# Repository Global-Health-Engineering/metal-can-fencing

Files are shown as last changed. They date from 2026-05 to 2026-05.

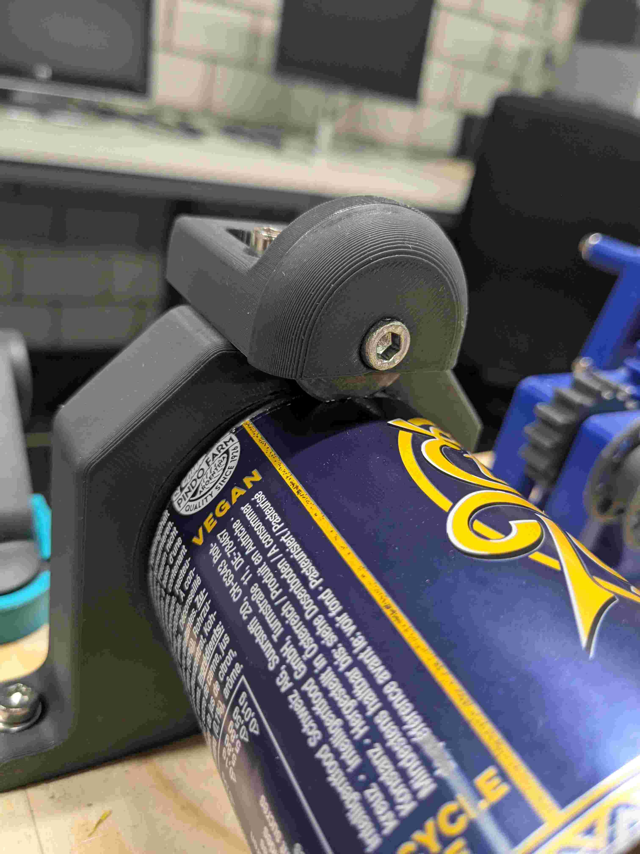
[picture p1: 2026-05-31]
media/photo/PXL_20260528_091816733.jpg

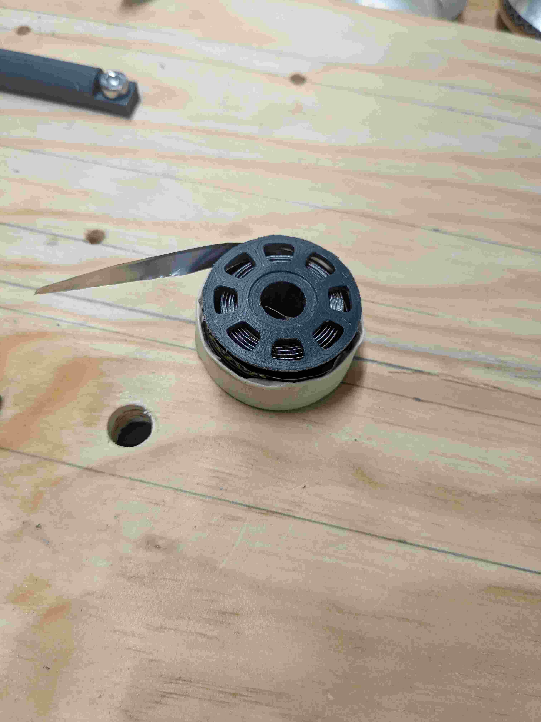
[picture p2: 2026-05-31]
media/photo/PXL_20260528_092012684.jpg

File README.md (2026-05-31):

# metal-can-fencing

# Aluminium Can Wire Prototype
**Semester Project at Global Health Engineering, ETH Zürich**

The repo contains the project files of a prototype machine for turning waste aluminium cans into wire intended to be used for fencing. A detailed description of the project background can be found in the proposal document. 

---

## CAD Model

The CAD Model of the protoype is available as a public document here:
**[Main Prototype CAD](https://cad.onshape.com/documents/85e6de6017a37f12d6a3c2e9/w/624e25fabe076b6094cd570a/e/ef13d64fd9b0a9b642ac96d9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)**

The .stl files are also available for download in the hardware folder of this repository.
A part list with everything necessary for the construction of the prototype is in the docs folder.

---
## Video Demonstration

**[Fencing Wire from Waste Cans: Prototype Demonstration](https://youtu.be/PfGfU24g3dw)**

---

## Repository Structure

```

├── docs/
│   ├── zanggerf_proposal.pdf   # Research proposal with background information on project
│   ├── part_list.xlsx         # List of all parts needed for the construction
|   └── parameter_testing.xslx  # Excel sheets of can dimensions, tested wire types and optimized parameters
│
├── media/
│   └── photo/  # Images of the prototype and different wire types tested
│
├── hardware/            #.stl files of the 3D printed parts of the prototype
|   ├── non_print_parts/      # Parts to be bought/manufactured not printed 
|   ├── opener/
|   ├── slicer/
|   ├── transmission/
|   └── twister/ 
│
└── README.md
```

---

## Contact

Feel free to contact Fabian Zangger (fabian.zangger@hotmail.com) if you have questions regarding the project.

---

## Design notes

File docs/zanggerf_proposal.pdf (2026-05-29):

June 2023 | 1 of 6

## Origami Fencing from Waste Cans

Fabian Zangger

Background

Solid Waste disposal in Sub-Saharan Africa

Proper management and disposal of solid waste is crucial, as open dumping and burning have enormous negative impacts both on public health and on the environment (Adedara et al., 2023; Ferronato & Torretta, 2019). The annual waste generation in sub-Saharan Africa has been increasing and is expected to keep doing so as populations and economies grow, while solid waste collection and coverage rates are still far below satisfactory at around 65% (Ferronato & Torretta, 2019).

Aluminium Recycling in Malawi

Aluminium and other scrap metal is collected in Malawi by waste pickers but is mostly exported to other countries rather than being recycled in Malawi (Kasinja & Tilley, 2018). It is also frequently turned into artisanal cookware, which is a health risk due to metal leaching into the food when using the

recycled cookware (Street et al., 2020).

Resource shortages in Malawi

Malawi suffers from resource shortages, leading to delays in construction projects and making construction materials essentially unavailable for many (Moses & Wynand, 2013). Theft of valuable resources such as aluminium cables only worsen the situation (Beston, 2025). Farmers that require fencing to protect their produce from grazing goats cannot afford to build a fence from conventional materials.

Requirements for goat suitable fencing

The practise of letting goats roam free leads to the problem of farmers crops being consumed and destroyed by the goats (Rumosa Gwaze et al., 2008). To protect the crops from the goat herds, suitable fencing must be used. The fencing must not present a danger to the goats, e.g. it mustn’t have sharp edges that injure the animals or have loose strings in which they can entangle and hurt themselves (Paige, 2008). At the same time, the fencing needs to be high enough to stop the goats from jumping it, and reach to the ground so the animals cannot slip under it (Lund & May, 2003).

Aluminium can upcycling

Various methods to upcycle aluminium beverage cans already exist and have been documented online. Project Kamp, a community research project for more sustainable living, has built a roof from shingles made up of aluminium cans that were cut up and flattened (Cheung & Hakkens, 2023). Keving Cheung designed a can slicer, intended to quickly and cleanly cut off the top and bottom parts of aluminium cans, leaving a sheet metal cylinder (Cheung, n.d.). Other creators turned used beverage cans into low voltage electric wiring (CircuitsReuse, n.d.) or even jewellery.

Problem statement and goals

Aluminium beverage cans in Malawi are being collected, but do not get recycled. Farmers need fencing to protect their crops from roaming goats, but can’t afford them. The goal of this project is to design a method to upcycle empty aluminium beverage cans into fencing. The fencing design has to be robust enough to hold back goats without posing an injury risk to the animals. A prototype machine for the cutting and folding of the cans is to be developed. The machine must be simple to manufacture in low resource environments and easy to operate and maintain.

Research Questions

1. How can aluminium beverage cans be turned into fencing suitable for managing goats?
2. What is the tensile strength that can be achieved with a fence made of aluminium wiring?
3. How can a machine facilitate and speed up the process of fence manufacturing?

Methods

1. Requirements for goat fencing will be researched and commercially available fencing designs will be studied. Aluminium beverage cans will be cut into strips or sheets. A method for interlocking the strips to form a wire will be determined experimentally. Inspiration from origami techniques could be used to find a satisfactory method. The aluminium wiring could then be woven into mesh to increase the fencings strength. Metrics to categorise the resulting fence designs could include the tensile strength, how much of an individual can can actually be used (or how much of it ends up as scrap), how many steps are required in the manufacturing process or how many cans are required per meter of fence.
2. The tensile strength of the resulting fence designs will be measured. Additionally, the durability to different kind of stresses could be tested, such as simulating goats chewing on the wiring or ramming it. This may be a crucial weakness, as the thin aluminium from the cans is very prone to fatigue fractures after bending just a few times.
3. For the resulting fencing design, the relevant manufacturing steps will be analysed. A machine will be designed to aid in carrying out the manufacturing steps. A prototype of the machine will be built and tested. The machine will be designed to be easy to manufacture from locally available resources. It will be portable and powered by hand (e.g. via a hand crank) to allow it to be used anywhere. The prototype of the machine could then be further improved and implemented in Blantyre, Malawi, as part of a master’s thesis. The prototype will presumably be built using 3D printed and / or laser cut parts, to allow for rapid prototyping.

Planning

Gantt chart

I am doing this semester project part time, from the 02.03. to the 29.05.

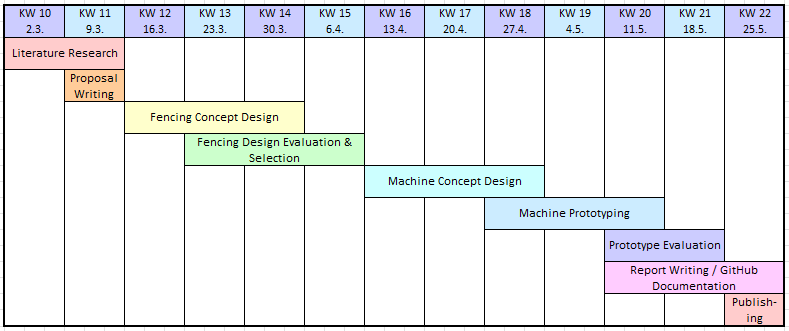
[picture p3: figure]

Figure 1. Gantt chart for research work and thesis writing.

After some initial research I will start to develop and build some fence concepts from cans by hand. The robustness and strength of the fence designs will then be tested and the results used to improve the designs. It may turn out that aluminium breaks to quickly from fatigue, which could be a potential showstopper. Once the best fence design is determined (one that is not too complex to build in as few as possible steps, yet robust enough), a concept for how to mechanise the production will be developed. I plan to start prototyping early and quickly using 3D printed parts. The last two to three weeks I will focus on evaluating the prototype and reporting my results. If the results are promising I would like to then continue with the project for my master’s thesis.

Data Management Plan (DMP)
Data collection

I am not planning to collect survey data. The only data I will be dealing with is the fencing designs and machine parts that will be developed. Some variables may be used to characterize and evaluate the fencing designs such as:

- Tensile strength
- Material cost (Cans / meter)
- Manufacturing complexity
- Efficiency in can usage (how much of a can is actually used for the fencing)

Data storage

The fence designs and their characteristic variables will be stored in an excel sheet, where they can easily be compared to each other. The CAD Drawings of the machine prototype will be stored in a GitHub repository that will be used to document the entire project.

Budget

I can only give a rough estimate for the costs of the prototype, but I expect to remain under 100 CHF for the total material costs. The main expenses will be the knives for the cutting of the aluminium, plywood to build a solid base and some screws and nuts to fit the parts together.

No | expense | amount | unit price [CHF] | total price [CHF]
1 | 3D Printing Filament | 1 kg | 20 | 20
2 | Knives / Razor Blades | 5 | 5 | 25
3 | Screws etc. | 20 | 2 | 40
4 | Plywood | 1 | 15 | 15
Total | 100
dataset | data type | data format | data documentation
Fence designs | Concepts of fencing designs | Drawings / Images | Stored in a document on GitHub repo
Fence Characteristics | Variables describing the performance of the fence designs: • Tensile strength • Material Cost • Manufacturing Complexity • Can usage Efficiency | Excel table | Stored in a document on GitHub repo
CAD Drawing | Model of the Machine | .stl files | Stored on GitHub repo

References

Adedara, M. L., Taiwo, R., & Bork, H.-R. (2023). Municipal Solid Waste Collection and Coverage

Rates in Sub-Saharan African Countries: A Comprehensive Systematic Review and Meta-

Analysis. Waste, 1(2), 389–413. https://doi.org/10.3390/waste1020024

Beston, L. (2025, November 24). The Power Thieves of Thyolo: Inside Malawi’s Silent War Against

Infrastructure Vandalism. Zodiak Malawi. https://zodiakmalawi.com/national-news/news-in-

the-southern-region/the-power-thieves-of-thyolo-inside-malawis-silent-war-against-

infrastructure-vandalism

Cheung, K. (n.d.). Can Slicer. Kevin Cheung. Retrieved 5 March 2026, from http://kevin-cheung.com

Cheung, K., & Hakkens, D. (2023). Aluminium Can Roof. Project Kamp Community.

https://community.projectkamp.com/research/can-we-make-a-roof-from-recycled-

aluminium-cans

CircuitsReuse, B. (n.d.). Repurposing Beverage Cans for Low Voltage Electrical Wiring.

Instructables. Retrieved 9 March 2026, from https://www.instructables.com/Repurposing-

Beverage-Cans-for-Low-Voltage-Electric/

Ferronato, N., & Torretta, V. (2019). Waste Mismanagement in Developing Countries: A Review of

Global Issues. International Journal of Environmental Research and Public Health, 16(6),

1060. https://doi.org/10.3390/ijerph16061060

Kasinja, C., & Tilley, E. (2018). Formalization of Informal Waste Pickers’ Cooperatives in Blantyre,

Malawi: | A | Feasibility | Assessment. | Sustainability, | 10(4), | 1149.

https://doi.org/10.3390/su10041149

Lund, | R., | & | May, | T. | (2003). | Goat | Fencing. | NSW | Agriculture.

https://www.dpi.nsw.gov.au/__data/assets/pdf_file/0005/178502/goat-fencing.pdf

Moses, K., & Wynand, S. (2013). Causes of delay in road construction projects in Malawi. Journal

of | the | South | African | Institution | of | Civil | Engineering, | 55(3).

https://www.scielo.org.za/pdf/jsaice/v55n3/09.pdf

Paige, C. (2008). A Landowner’s Guide to Wildlife Friendly Fences. Montana Fish, WIldlife & Parks.

https://www.nrcs.usda.gov/sites/default/files/2022-09/WildlifeFriendlyFences.pdf

Rumosa Gwaze, F., Chimonyo, M., & Dzama, K. (2008). Communal goat production in Southern

Africa: | A | review. | Tropical | Animal | Health | and | Production, | 41(7), | 1157.

https://doi.org/10.1007/s11250-008-9296-1

Street, R. A., Mathee, A., Tanda, S., Hauzenberger, C., Naidoo, S., & Goessler, W. (2020). Recycling

of scrap metal into artisanal cookware in the informal sector: A public health threat from multi

metal exposure in South Africa. Science of The Total Environment, 699, 134324.

https://doi.org/10.1016/j.scitotenv.2019.134324

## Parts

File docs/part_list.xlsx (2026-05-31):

Part Name | File name | Amount required | How to make | Link | Description
Baseplate | baseplate.stl | 1 | cut to shape and drill holes according to drawing |  | 10 mm Wooden plate on which everything is mounted
Can Clamp | can_clamp.stl | 1 | print and insert m3 threaded inserts |  | Clamp to mount can on axis
Opener Bottom | opener_bottom.stl | 1 | print |  | blade holder for opening mechanism bottom
Opener Bottom Cover | opener_bottom_cover.stl | 1 | print |  | Blade cover for bottom of opener
Opener Top Half | opener_top.stl | 1 | print |  | Top half of opener
Opener Top Cover | opener_top_cover.stl | 1 | print |  | Blade cover for top of opener
Rail | rail.stl | 2 | print |  | Rail to guide opener along axis
M10x80 Hex Screw |  | 3 | buy | https://www.hornbach.de/p/sechskantschraube-m-schaft-din-931-m10x80-mm-galv-verzinkt-50-stueck/5217648/ | Used as axes for opened height adjustmen and for the gearbox
M3 Heat Set Inserts |  | 4 | buy | https://www.amazon.com/Kadrick-Threaded-Assortment-Printing-Components/dp/B0DLSLJSK7 | Used to secure that can wont rotate inside clamp and for crank handle
M5x30 Allen Screw |  | 20 | buy | https://www.hornbach.ch/de/p/dresselhaus-innensechskantschraube-zylinderkopf-antrieb-teilgewinde-5-0-x-30-mm-galvanisch-verzinkt-100-stueck/6834955/ | Used for almost all connections to baseplate and to mount blades
M5 Hex Nut |  | 20 | buy | https://www.hornbach.ch/de/p/sechskantmutter-din-934-m5-galv-verzinkt-100-stueck/3830634/ | '
M5 Washer |  | 20 | buy | https://www.hornbach.ch/de/p/unterlegscheibe-din-9021-5-3-mm-edelstahl-a2-100-stueck/3836695/
Olfa RB28-2 |  | 5 | buy | https://www.hornbach.ch/de/p/olfa-ersatzrundklingen-rb28-2-2er-pack/3896117/ | Circular blades to
Can Slicer Base | slicer_base.stl | 1 | print |  | Mounts slicer tube to baseplate
Slicer Tube | slicer_tube.stl | 1 | print, then cut 0.6mm groove at 2° to fit blade |  | guide for can cylinder during slicing
Slicer Blade Mount | blade_mount.stl | 1 | print, insert m5 heat set insert |  | adjustable blade mount to allow for different thickness of strip
M5 Heat Set Insert |  | 3 | buy | https://www.amazon.com/Kadrick-Threaded-Assortment-Printing-Components/dp/B0DLSLJSK7 | used to mount blade on slicer
Slicer Blade Cover | slicer_blade_cover.stl | 1 | print |  | covers blade to protect fingers
Coil Center | coil_center.stl | 1 | print |  | center of coil that winds up sliced strips
Coil Wall | coil_wall.stl | 2 | print, then glue to center with fillet to inside |  | walls of coil
Coil Sleeve | coil_sleeve.stl | 1 | print |  | sleeve for coil to prevent unwinding by itself
Twister Axle | twister_axle.stl | 1 | print |  | axle to mount full coil on
Twister Lever | twister_lever.stl | 1 | print, then insert m3 threaded insert |  | lever to off center coil for spinning
Wire Guide | wire_guide.stl | 1 | print |  | guides the wire while twisting
Gearbox Mount Crankside | gearbox_mount_crankside.stl | 1 | print |  | guides for the axes
Gearbox Mount Coilside | gearbox_mount_coilside.stl | 1 | print |  | guides for the axes
Coil Axle | coil_axle.stl | 1 | print |  | axle to mount coil on
45 Teeth Gear | gear_45.stl | 1 | print, secure on axis with nuts |  | 45 teethed gear to speed up machine
15 Teeth Gear | gear_15.stl | 1 | print |  | 15 teethed gear
Hex Crank | hex_crank.stl | 1 | print, thread onto hex screw axle & fix with inserts |  | lever handle to spin axis
Handle m5 | handle_m5.stl | 1 | print, attach to crank with m5 screw |  | handle to grip onto
Prusa Adapter | prusa_adapter.stl | 1 | print |  | adapter for prusament spool to fix it on baseplate for wire winding
Axle 50mm | axle_50mm.stl | 1 | print |  | axle to mount filament spool on

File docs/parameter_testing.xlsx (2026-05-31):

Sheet: Can Dimensions
Can Type | Diameter [mm] | Height [mm] | Bottom Height [mm] | Top Height [mm] | Bottom Ring Diameter [mm] | Top Ring Diameter [mm] | Volume [ml] | Usable Height [mm] | Usable Area [mm^2] | Brands | Circumference | desired String Thickness | Required Knife Angle
Wide Short | 66 | 116.5 | 10 | 17 | 47 | 52 | 330 | 89.5 | 24155.70591 | El Tony | 207.3451151 | 6 | 1.657520458
Slim Tall | 57 | 145 | 6 | 10 | 46 | 51 | 330 | 129 | 25965.26328 | Uludag | 179.0707813 | 6 | 1.919051855
Wide Tall | 66 | 163 | 10 | 11 | 47 | 53 | 500 | 142 | 33797.25377 | Quöllfrisch, Somersby | 207.3451151 | 6 | 1.657520458
Medium Tall | 57.5 | 157 | 6 | 10 | 47 | 52 | 355 | 141 | 28360.72768 |  | 180.6415776 | 6 | 1.902376763

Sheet: Stats
 |  | Days without injuring my hands:
 |  | 0
Cans Cut apart: | Fingers cut:
125 | 13

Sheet: Testing
Testing Arrangement: |  | Test Strip of 50 cm length |  | Attached to carabiners at both ends, suspended. Increasing weights are added to test the tensile strength.
 |  |  |  |  |  |  |  | cans used: mate
Fence Name | Wire Type | Connection Type | Fence Type | Tensile Strength with connection | without connection | Weaknesses | Manufacturing Complexity | Material Cost (meters/can) |  | Consider?
Knotted Loops | <10 mm Loops | Cow Hitch Knot | tbd | < 1 kg |  | Low Tensile Strength | Difficult to cut cans into rings, how to automate then? | 0.62 |  | no, too weak and complex
Linked Loops | <10 mm Loops |  |  | < 1 kg | connections easy | difficult to cut loops | high | 0.42 |  | no, too weak and complex
Double Folded | 15 mm strip | folding hooks |  | 5.2 kg |  | difficult to bend, rips | medium, possible to automate | 0.95 |  | no
Triple folded | 15 mm strip | folding hooks |  | 9.8 kg |  | broken at connection | medium, possible to automate | 0.92 |  | maybe
Twisted | 6 mm strip | can caps |  | 4.1 kg | 9.2 |  |  | 1.45 |  | yes
Twisted Double | 6 mm strip | can caps |  |  |  | difficult to connect, as is quite thick |  | 0.75 |  | no, too costly
Twisted Triple | 6 mm strip | can caps |  |  |  | hard to connect with caps | quite complicated | 0.52 |  | no, too complex
Rolled | 6 mm strip |  |  | strong but breaks instantly when bent |  |  |  |  |  | no
Twisted | 6 mm strip | fishermans knot |  | 8.0 kg
twisted shows best results in efficiency, good strength and is still flexible for bending/winding onto spools -> clearly best option
now: find optimal width of aluminium strips for twisting
strip width | resulting wire width | strength test | buckling radius | notes |  |  |  | optimal parameters:
1.8 | 1 mm |  | 8 mm | very fine wire, but not strong and at the limit of being able to be cut (thinnest achievable strips) |  |  |  | strip width | 5 mm
4 | 1.5 mm |  | 35 mm | fine wire, decent strength, no problems in twisting |  |  |  | cutting angle | 1.8°
4.5 | 1.8 mm |  | 40 mm | springy wire, |  |  |  | knife depth
5.5 | 2.2 mm |  | 50 mm | slight overlap starting?
6 | 2.3 mm |  | 45 mm | overlaps, helping against buckling?
7 | 2.6 mm |  | 70 mm
9 | 3 mm |  | ? | hard to twist smoothly, buckles appear
finding optimal angle
 |  | unterlagsscheiben
angle | comments |  |  |  |  | requried pulling force
0° | no "vortrieb", can doesn't move along | 1 |  | angle definitely required!
1° | sufficient vortrieb vor 6 mm strips | 1 |  |  |  | 9.5 N
2° | can moves along nicely | 1 | pulling straight gives best results |  |  | 8 N
3° | works well | 1 | "" |  |  | 9.5 N
4° | works well | 1 |  |  |  | 14 N
5° | works well | 1 |  |  |  | 18 N
6° | works well | 1 |  |  |  | 16.5 N
7° | starts to get stuck more often | 1 |  |  |  | 20 N
ideal angle: between 1 and 3 degrees, according to calculations it is 1.66° for wide cans and 1.92° for slim cans, so a value of 1.8 as a compromise should work well. Tests of force required for various angles validate the calculations
next: Optimizing the blade |  | Blade overlap
2° |  | 4 |  |  |  | 9 N
 |  | 2.8 |  |  |  | 9 N
 |  | 1.6 |  |  |  | 7 N
 |  | 0.4 |  |  |  | doesnt cut it anymore
 |  | 1 |  |  |  | 6.5 N

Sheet: Cutter Performance
Version | # of cans | Time | Time per can
Double Rotary Cutter | 5 | 325 | 65.0
Double Rotary Cutter | 7 | 402 | 57.4
Quadruple Rotary | 8 | 348 | 43.5
Quadruple Rotary | 5 | 222 | 44.4
Quadruple Rotary | 9 | 457 | 50.8

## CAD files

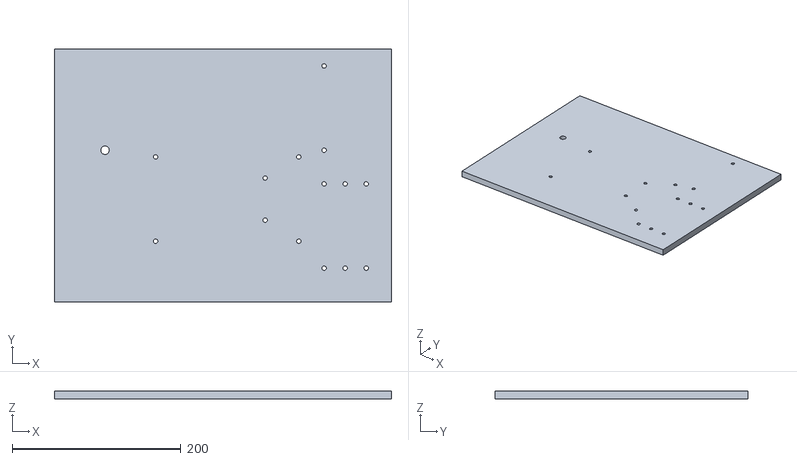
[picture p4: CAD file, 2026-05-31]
hardware/non_print_parts/baseplate.stl
400.0 x 300.0 x 10.0

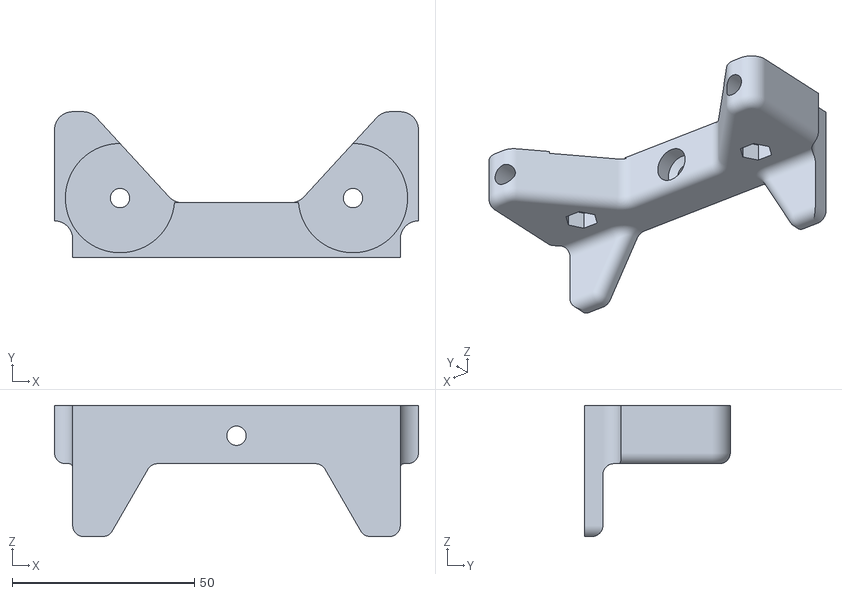
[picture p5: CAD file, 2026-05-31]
hardware/opener/opener_bottom.stl
100.0 x 40.0 x 36.0

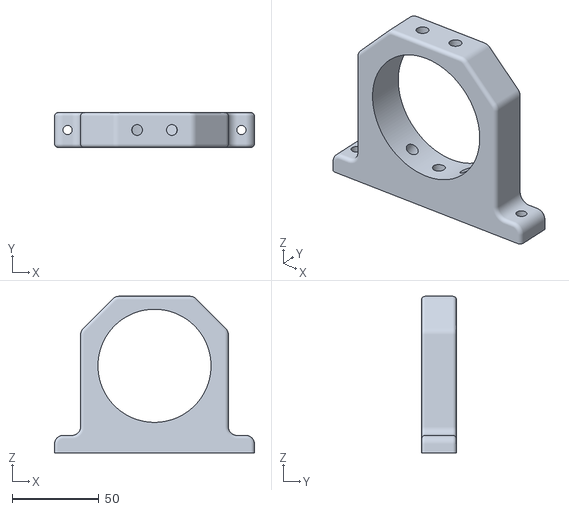
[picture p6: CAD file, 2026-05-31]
hardware/slicer/slicer_base.stl
115.0 x 20.0 x 90.0

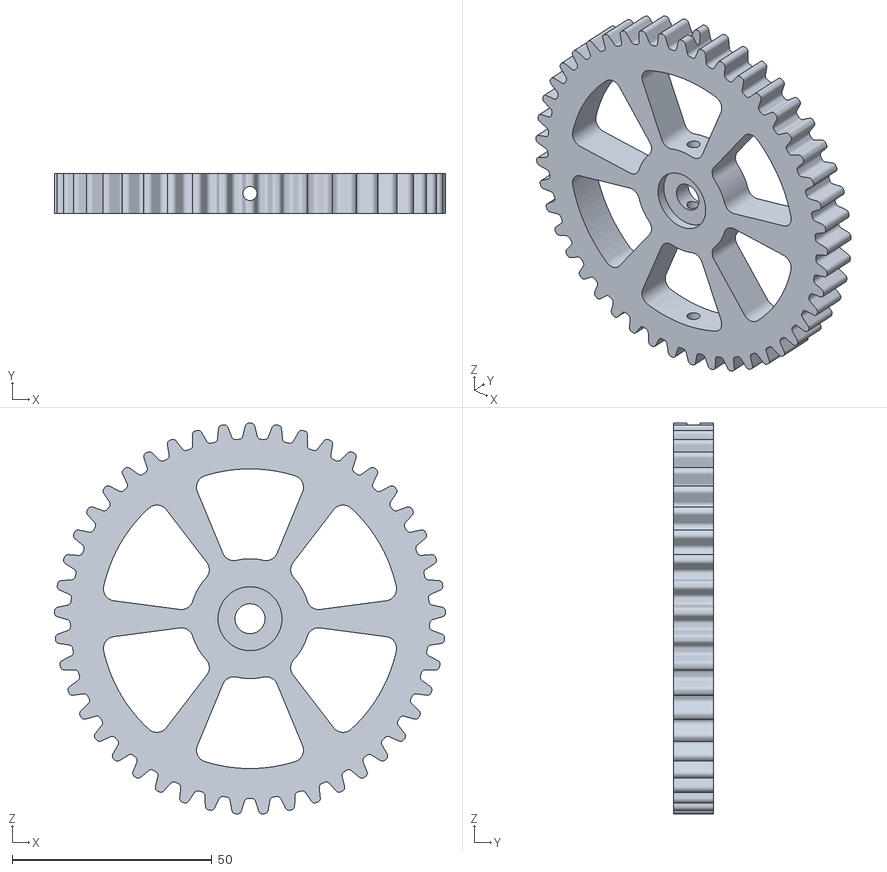
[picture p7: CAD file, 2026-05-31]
hardware/transmission/gear_45.stl
97.9 x 10.0 x 97.8

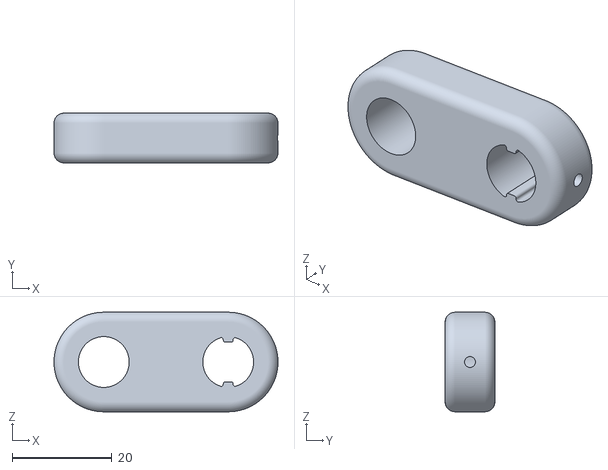
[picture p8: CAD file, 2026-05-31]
hardware/twister/twister_lever.stl
45.0 x 10.0 x 20.0

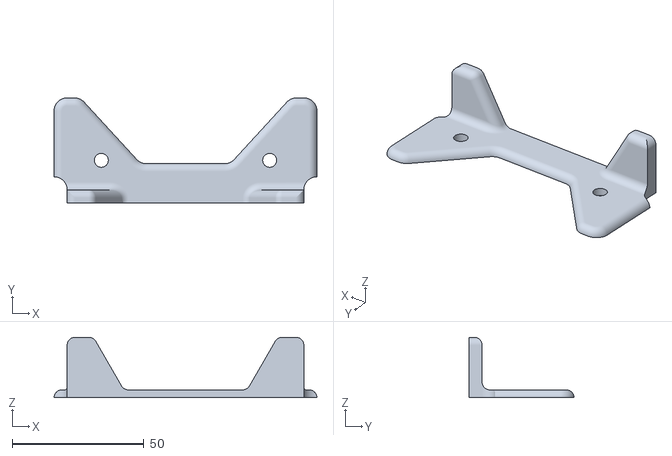
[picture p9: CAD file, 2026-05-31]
hardware/opener/opener_bottom_cover.stl
100.0 x 40.0 x 23.0

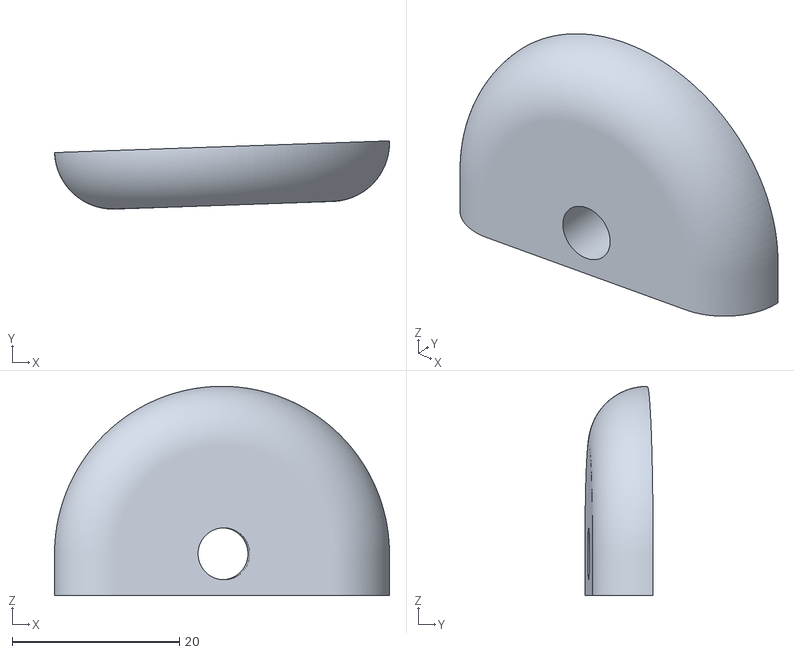
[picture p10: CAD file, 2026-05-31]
hardware/slicer/slicer_blade_cover.stl
40.0 x 8.15 x 25.0

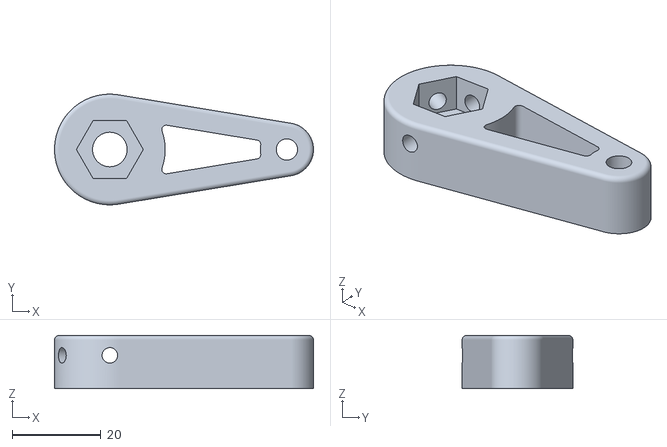
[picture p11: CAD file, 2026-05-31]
hardware/transmission/hex_crank.stl
58.5 x 25.0 x 12.0

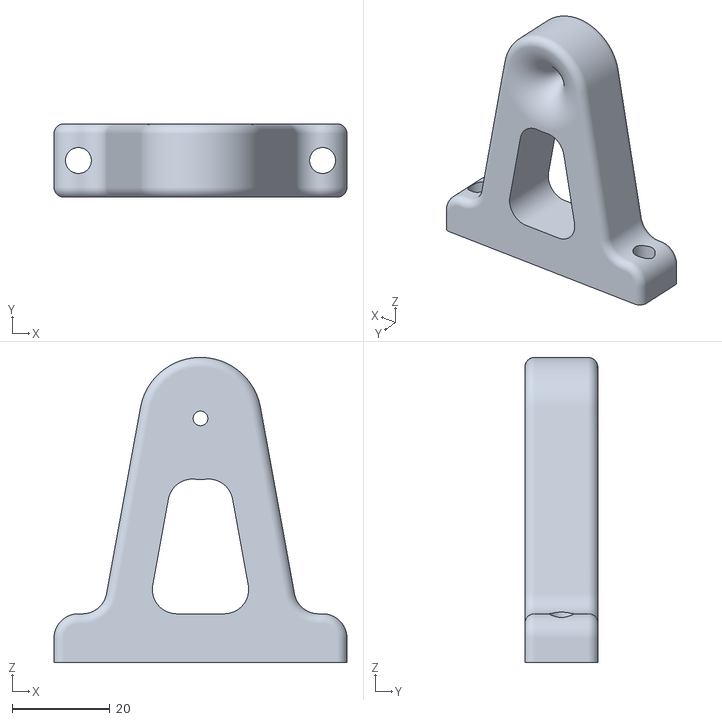
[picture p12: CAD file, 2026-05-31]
hardware/twister/wire_guide.stl
60.0 x 15.0 x 62.5

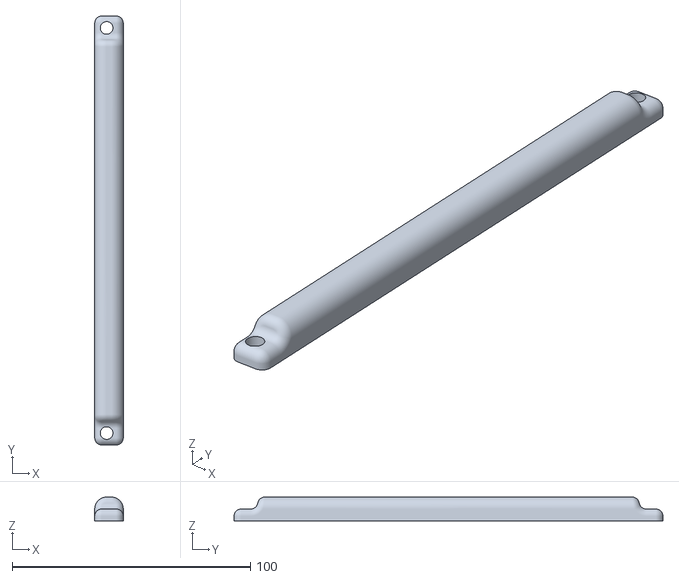
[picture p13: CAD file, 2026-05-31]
hardware/opener/rail.stl
12.0 x 180.0 x 10.0

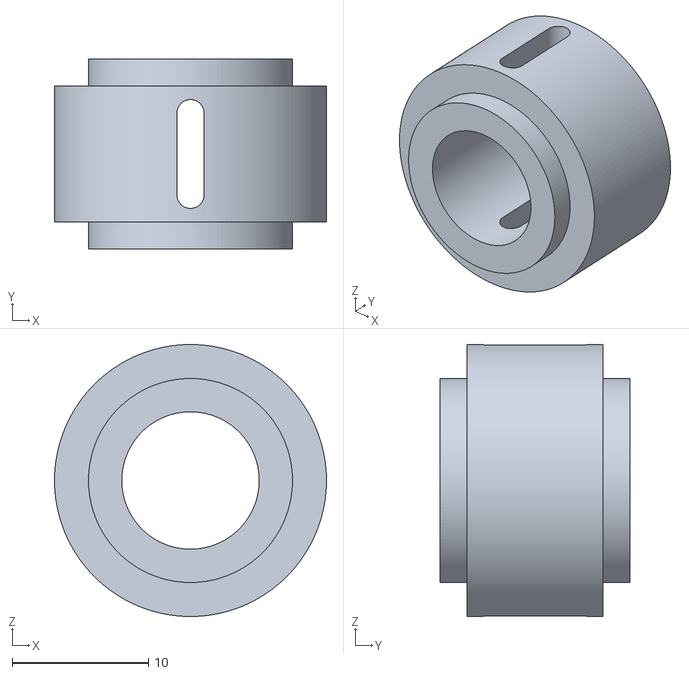
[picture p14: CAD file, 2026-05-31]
hardware/slicer/coil_center.stl
20.0 x 14.0 x 20.0

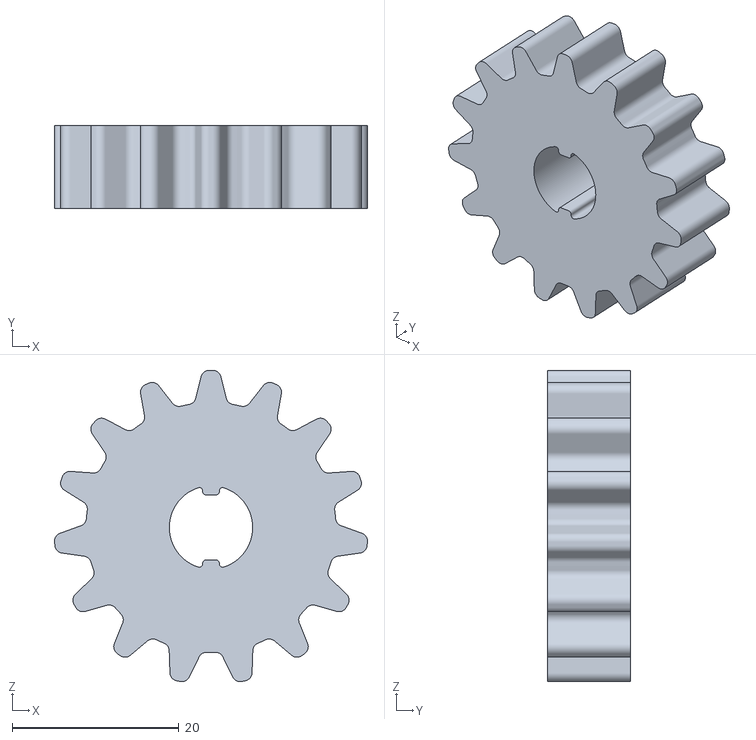
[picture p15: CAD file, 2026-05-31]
hardware/transmission/gear_15.stl
37.6 x 10.0 x 37.4

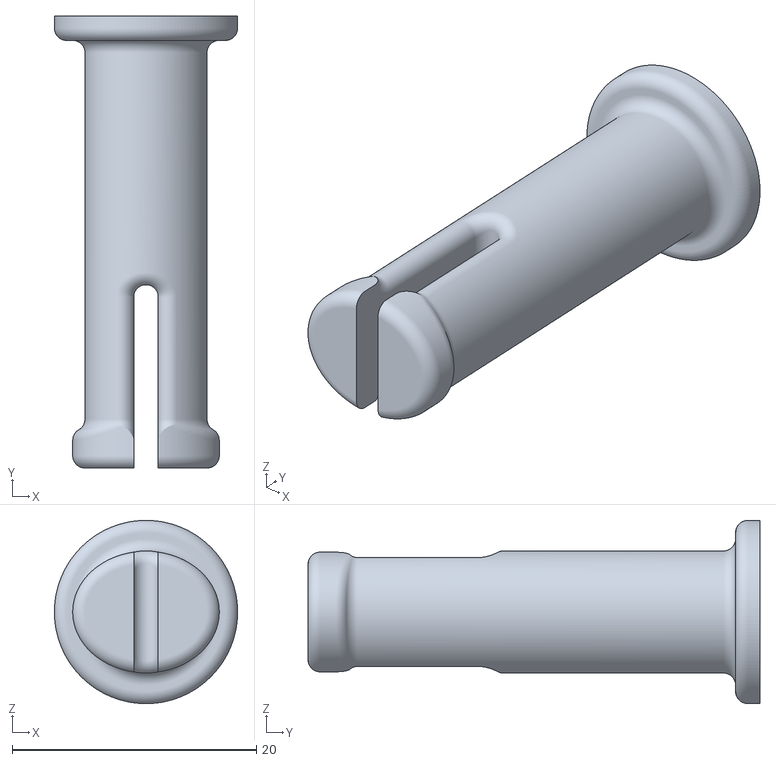
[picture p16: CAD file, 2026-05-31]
hardware/twister/twister_axle.stl
15.0 x 37.0 x 15.0

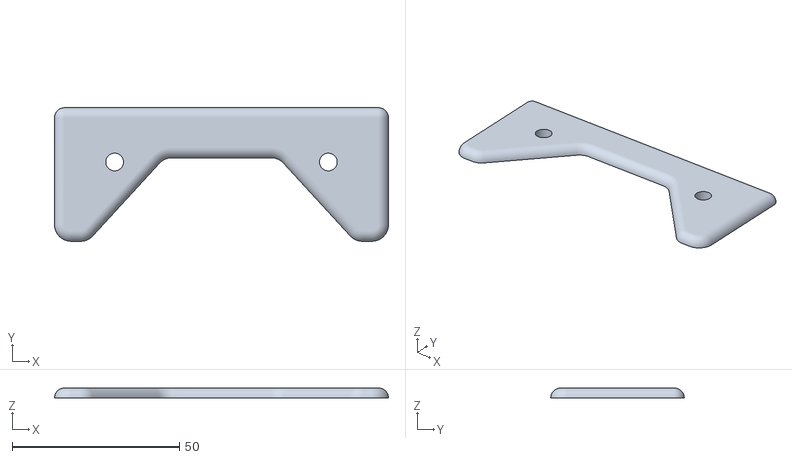
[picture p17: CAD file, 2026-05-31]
hardware/opener/opener_top_cover.stl
100.0 x 40.0 x 3.00

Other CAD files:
hardware/slicer/coil_wall.stl
hardware/transmission/gearbox_mount_crankside.stl
hardware/twister/prusa_adapter.stl
hardware/opener/opener_top.stl
hardware/opener/can_clamp.stl
hardware/slicer/blade_mount.stl
hardware/slicer/slicer_tube.stl
hardware/transmission/axle_50mm.stl
hardware/transmission/coil_axle.stl
hardware/transmission/gearbox_mount_coilside.stl
hardware/transmission/handle_m5.stl
hardware/twister/coil_sleeve.stl
